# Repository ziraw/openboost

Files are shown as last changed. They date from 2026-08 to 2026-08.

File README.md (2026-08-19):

# Open Source Boost Controller w/ ESP32-C3 SuperMini.  
This is REV2.0 fixing the mistakes of my previous PCB design, it's currently not field tested. 

**The Code was mainly written by an LLM, since I'm extremely inexperienced with coding, please be advised that this is not in any way "safe" to hook up to your engine, please take a minute and review the code yourself and decide for yourself. If you find anything that you might want to change I'm more than happy to see a PR opened!**  
speaking of code, the 2 LEDs are currently not in use.

I'm grabbing the MAP signal off of my gauge atm, which seems to work perfectly fine. You can theoretically hook up a separate sensor to the board itself if you want, although I would never ever use any sort of boost controller without an actual gauge!  

### I/O
It has a 5V output and a sensor passthrough on the JST connector, alongside the main I/O;  
1 - 12V  
2 - GND  
3 - SENS I/O  
4 - SENS I/O  
5 - 5V  
6 - VALVE  

The controller sits between the Valves GND connection and the Chassis to switch it at ~28hz via a PWM signal generated by a PID controller running on the ESP32.
To set Parameters (PID and Boost) it runs a Webserver on it's own WIFI network, which is kind of tedious, but I might add physical controls too a future version, for now the aim of this project is to keep it as **cheap and accessible as possible.**
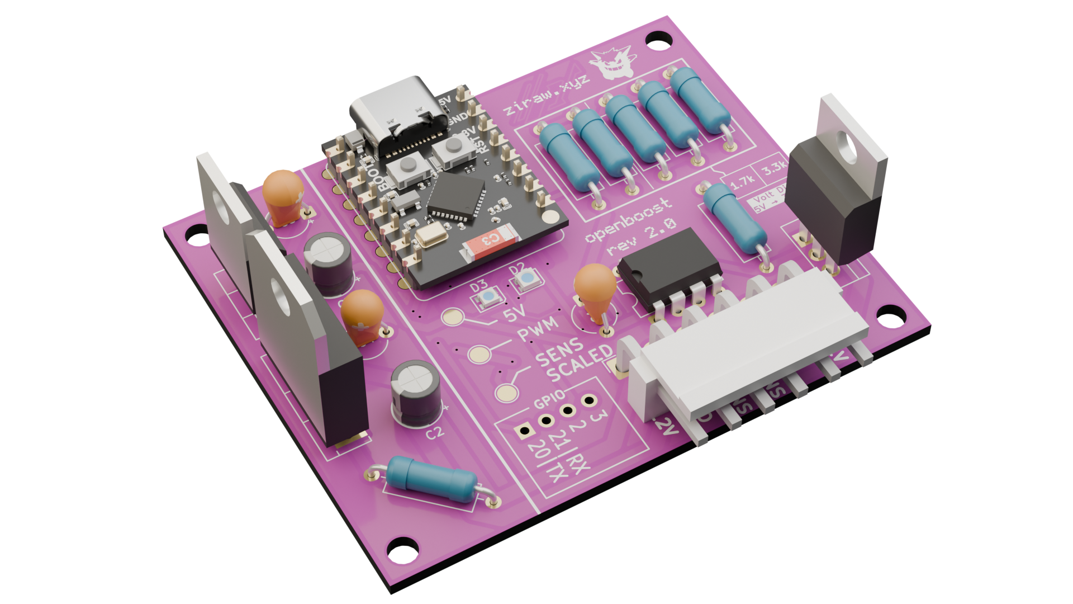
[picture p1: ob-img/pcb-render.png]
3D Render

### BOM (THT unless Specified):
- ESP32-C3 SuperMini  
- IRLZ44N  
- TC4422  
- TIP2955  
- L7805  
- 6P JST-VH Horizontal Connector  
- 2x SMD 2020 WS2812B (not used in Code atm)  
- Various Resistors  
- 2x220uF 16V  
- 3x100nF Ceramic  
- 1N4007 Diode (at Boost Valve)  
- (Pin Sockets for ESP32)

Valve used at Wastegate: BMW N75 Boost Control Valve (on a CA18DET Engine), although any suitable boost/mac valve should be fine to use. You have to hook up above mentioned flyback diode directly to the pins of the valve.

Link to my original reddit post from rev 1: https://www.reddit.com/r/esp32/comments/1vrntt0/i_made_a_boost_controller_with_a_esp32c3_first/

### Schematics
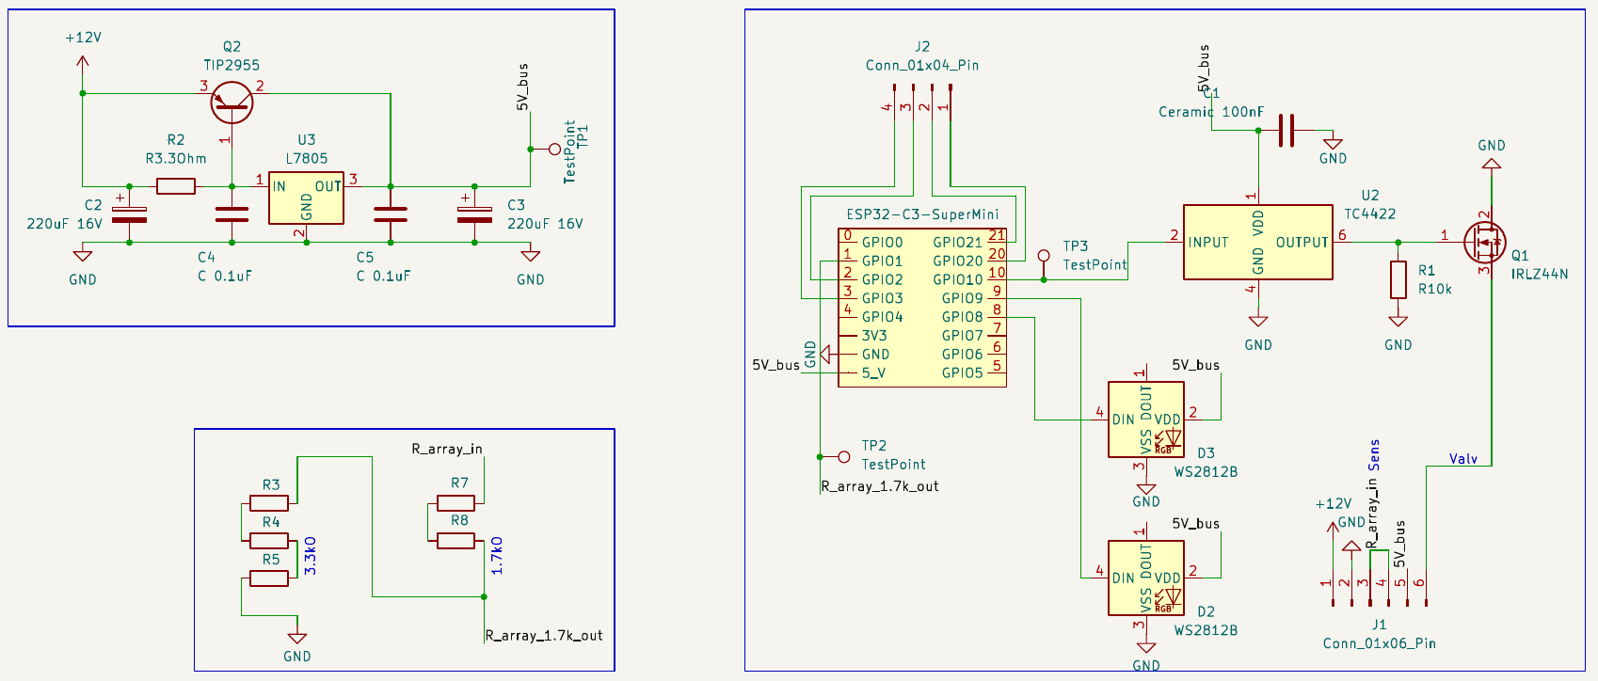
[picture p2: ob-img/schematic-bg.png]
Schematic

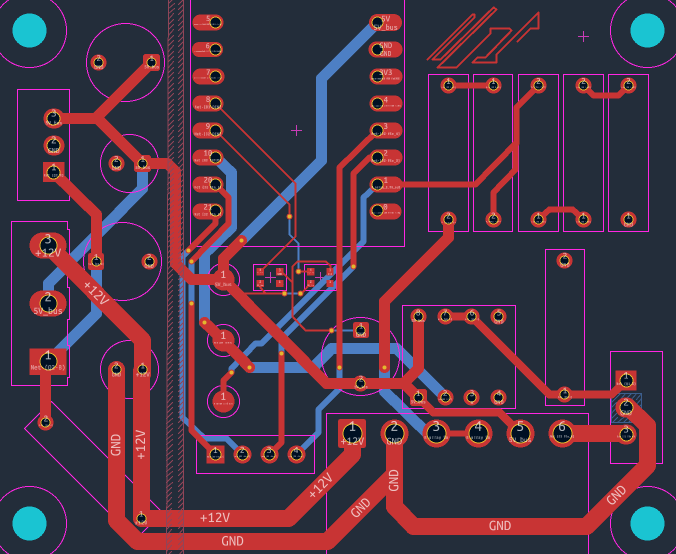
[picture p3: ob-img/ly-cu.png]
CU Layer


Feel free to DM me on reddit: /u/ziraw_tech

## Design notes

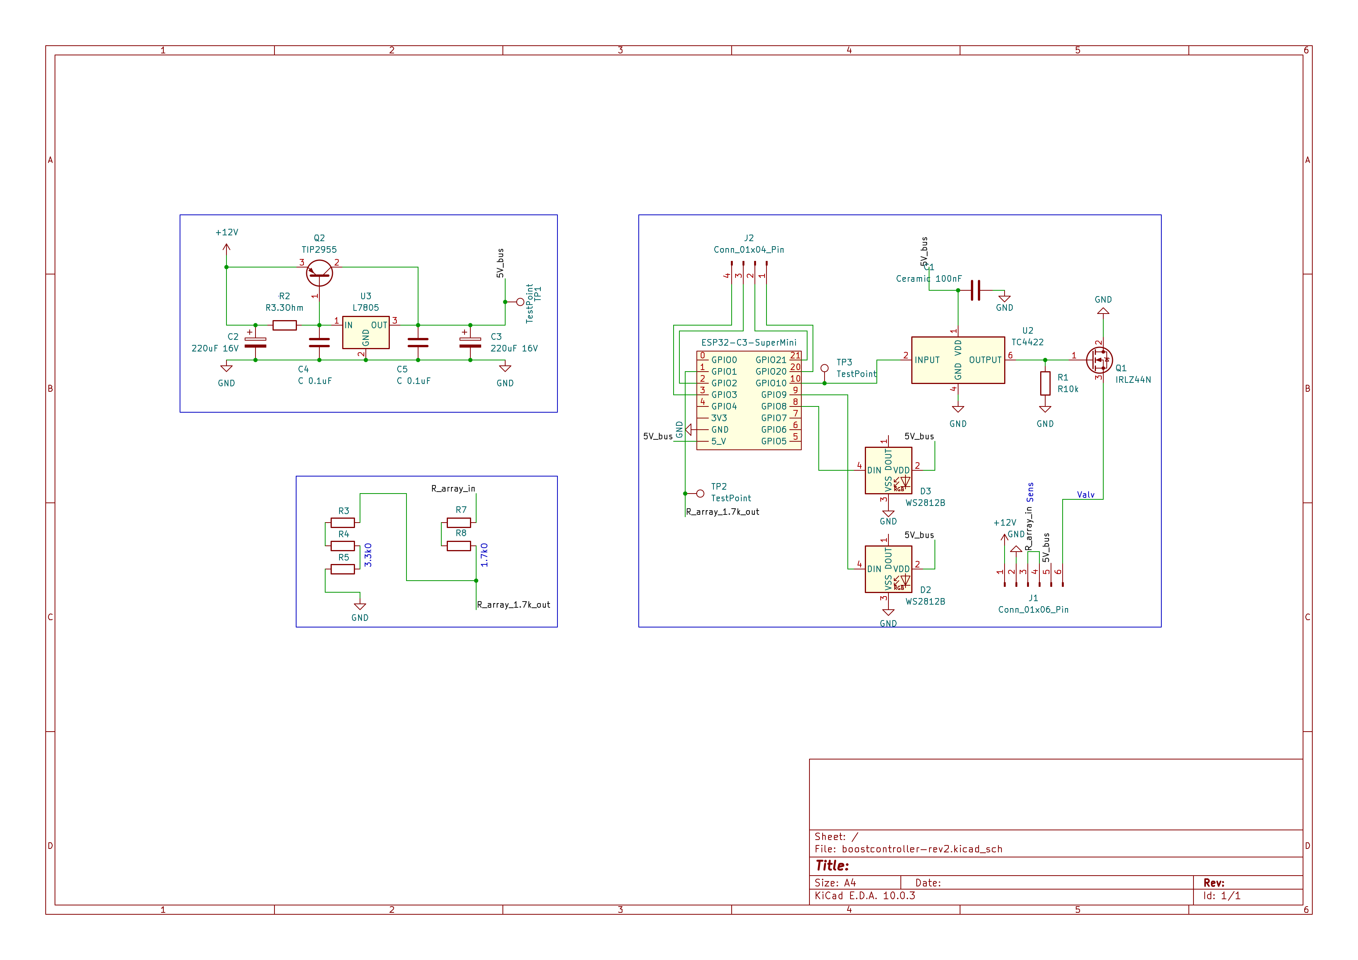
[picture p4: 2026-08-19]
ob-img/schematic.png

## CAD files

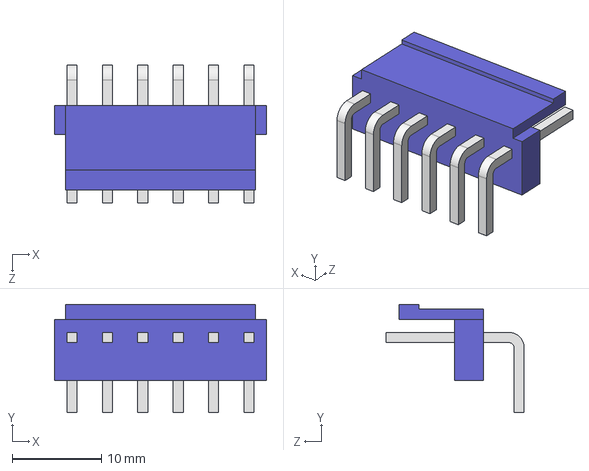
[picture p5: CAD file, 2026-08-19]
3D/B6PS-VH.STEP
23.7 x 12.1 x 15.5 mm

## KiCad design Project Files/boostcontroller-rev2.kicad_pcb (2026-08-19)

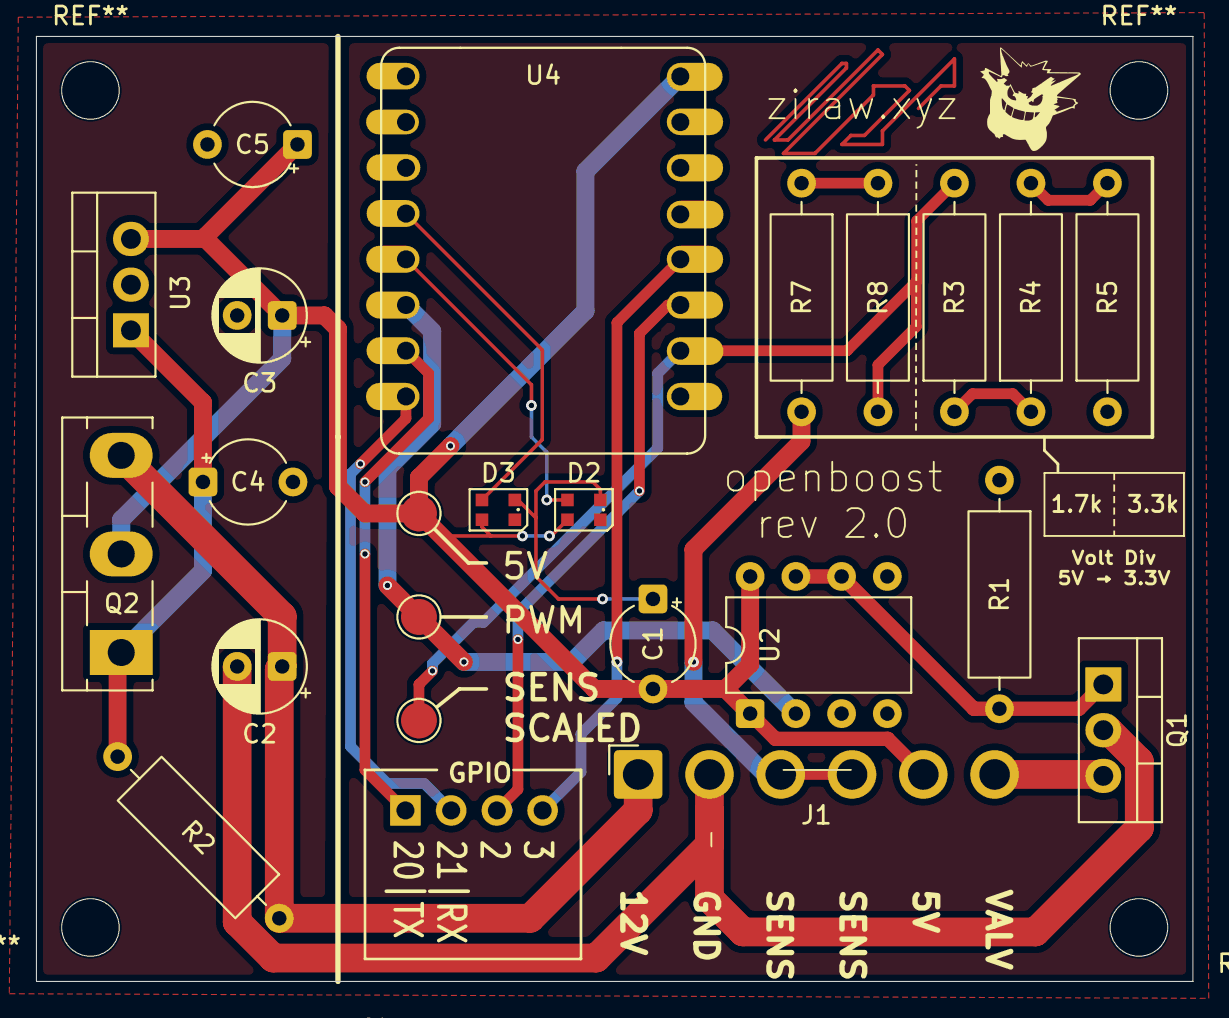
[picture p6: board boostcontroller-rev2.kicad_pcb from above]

Board: 2 copper layers, 64.2 x 52.5 mm, 24 parts (0 on the bottom side), 18 nets.

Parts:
C1: Ceramic 100nF; CP_Radial_Tantal_D4.5mm_P5.00mm
C2, C3: 220uF 16V; CP_Radial_D5.0mm_P2.50mm
C4, C5: C 0.1uF; CP_Radial_Tantal_D4.5mm_P5.00mm
D2, D3: WS2812B; LED_WS2812B-2020_PLCC4_2.0x2.0mm
J1: Conn_01x06_Pin; JST_VH_B6PS-VH_1x06_P3.96mm_Horizontal
J2: Conn_01x04_Pin; PinHeader_1x04_P2.54mm_Vertical
Q1: IRLZ44N; TO-220-3_Vertical
Q2: TIP2955; TO-218-3_Vertical
R1: R10k; R_Axial_DIN0309_L9.0mm_D3.2mm_P12.70mm_Horizontal
R2: R3.3Ohm; R_Axial_DIN0309_L9.0mm_D3.2mm_P12.70mm_Horizontal
R3, R4, R5, R7, R8: R_Axial_DIN0309_L9.0mm_D3.2mm_P12.70mm_Horizontal
TP1, TP2, TP3: TestPoint; TestPoint_Pad_D2.0mm
U2: TC4422; DIP-8_W7.62mm
U3: L7805; TO-220-3_Vertical
U4: ESP32-C3-SuperMini; ESP32-S3-SuperMini

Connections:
+12V: C2.1, J1.1, Q2.3 (E), R2.1
/5V_bus: C1.2, C3.1, C5.1, D2.2 (VDD), D3.2 (VDD), J1.5, Q2.2 (C), TP1.1 (1_1), U2.1 (VDD), U2.8 (VDD), U3.3 (OUT), U4.5V (5_V)
/R_array_1.7k_out: R3.2, R8.2, TP2.1 (1_1), U4.1 (GPIO1)
/R_array_in: J1.3, J1.4, R7.2
GND: C1.1, C2.2, C3.2, C4.2, C5.2, D2.3 (VSS), D3.3 (VSS), J1.2, Q1.2 (D), R1.2, R5.1, U2.4 (GND), U2.5 (GND), U3.2 (GND), U4.GND
unnamed: D2.4 (DIN), U4.9 (GPIO9)
unnamed: D3.4 (DIN), U4.8 (GPIO8)
unnamed: J1.6, Q1.3 (S)
unnamed: J2.1, U4.20 (GPIO20)
unnamed: J2.2, U4.21 (GPIO21)
unnamed: J2.3, U4.2 (GPIO2)
unnamed: J2.4, U4.3 (GPIO3)
unnamed: Q1.1 (G), R1.1, U2.6 (OUTPUT), U2.7 (OUTPUT)
unnamed: C4.1, Q2.1 (B), R2.2, U3.1 (IN)
unnamed: R3.1, R4.1
unnamed: R4.2, R5.2
unnamed: R7.1, R8.1
unnamed: TP3.1 (1_1), U2.2 (INPUT), U4.10 (GPIO10)

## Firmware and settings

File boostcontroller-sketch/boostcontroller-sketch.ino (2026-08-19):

/*
 * ESP32 PID Pressure Controller — Normally-Open Solenoid Valve controlling wastegate
 *
 * Sensor:   0–3.3 V = -1 to +4 bar (raw), then divided by 1.1 for adjustment
 *           → effective display range -1 to ~3.6 bar
 * ADC:      GPIO1
 * MOSFET:   GPIO10  (PWM, max. ~20 kHz(is @ ~20-30hz), 10-bit)
 *           0% duty  = valve fully open  (pressure falls)   → 100% OPEN display
 *           100% duty = valve fully closed (pressure rises) →   0% OPEN display
 *
 * WEB:     http://192.168.4.1
 */

#include <WiFi.h>
#include <WebServer.h>

// ─── WiFi AP credentials ──────────────────────────────────────────────────────
const char* AP_SSID     = "BoostConfig";

// ─── Pin definitions ──────────────────────────────────────────────────────────
#define PIN_ADC   1
#define PIN_PWM   10

// ─── PWM config ───────────────────────────────────────────────────────────────
#define PWM_FREQ  28      // Hz
#define PWM_RES   10      // 10-bit → 0–1023

// ─── Sensor scaling ───────────────────────────────────────────────────────────
// 0 V → -1 bar,  3.3 V → +4 bar  (span = 5 bar over 3.3 V)
// Then divided by 1.1 for physical calibration adjustment
#define PRESSURE_AT_0V    -1.0f   // bar when ADC reads 0 V
#define PRESSURE_AT_3V3   +4.0f   // bar when ADC reads 3.3 V
#define PRESSURE_ADJUST    1.1f   // divisor for calibration

inline float voltsToPressure(float v) {
  float raw = PRESSURE_AT_0V +
              (v / 3.3f) * (PRESSURE_AT_3V3 - PRESSURE_AT_0V);
  return raw / PRESSURE_ADJUST;
}

// ─── PID parameters ───────────────────────────────────────────────────────────
//
//  Tuning direction:
//    Too slow to reach setpoint → raise Kp
//    Oscillates around setpoint → lower Kp, then raise Kd
//    Steady-state offset remains → raise Ki
//    Noisy / chattery valve     → lower Kd
//
float Kp       =  50.0f;
float Ki       =   0.5f;
float Kd       =   0.0f;
float setpoint =   0.95f;   // bar (within -1 … ~3.6 bar)
float outMin   =  -0.0f;    // PWM counts
float outMax   =   511.0f;

// ─── PID state ────────────────────────────────────────────────────────────────
float  integral      = 0.0f;
float  lastInput_bar = 0.0f;
float  pidOutput     = 0.0f;   // 0–1023 (pre-inversion)
float  pressure_bar  = 0.0f;
float  adcVolts      = 0.0f;
unsigned long lastPIDTime = 0;
#define PID_INTERVAL_MS 10     // 100 Hz

// ─── Pressure history for graph (60 s × 2 Hz = 120 samples) ──────────────────
#define HIST_LEN  120
float  pressHist[HIST_LEN];
float  spHist[HIST_LEN];
int    histIdx   = 0;
bool   histFull  = false;
unsigned long lastHistTime = 0;
#define HIST_INTERVAL_MS 500   // store one sample every 500 ms → 60 s window

// ─── Web server ───────────────────────────────────────────────────────────────
WebServer server(80);

// ─── PID compute ─────────────────────────────────────────────────────────────
void computePID() {
  unsigned long now = millis();
  float dt = (now - lastPIDTime) / 1000.0f;
  if (dt < (PID_INTERVAL_MS / 1000.0f)) return;
  lastPIDTime = now;

  // Read ADC — 8-sample average
  int raw = 0;
  for (int i = 0; i < 8; i++) raw += analogRead(PIN_ADC);
  raw /= 8;
  adcVolts     = raw * (3.3f / 4095.0f);
  pressure_bar = voltsToPressure(adcVolts);

  
  // Derivative on measurement (avoids setpoint-change kick)
  float dInput = (pressure_bar - lastInput_bar) / dt;
  float error = setpoint - pressure_bar;

  // Integral with anti-windup
 float pidUnsat = Kp * error + integral - Kd * dInput;
    if (pidUnsat > outMin && pidUnsat < outMax) {
        
        integral += Ki * error * dt;

}


integral  = constrain(integral, -400.0f, 400.0f);
pidOutput = constrain(pidUnsat, outMin, outMax);


  // ── push PWM signal  ───────────────────────────────────────
  uint32_t pwmVal = (uint32_t)pidOutput;

  // safety, if boost is over 0.12 bar over target, valve open.

  if((pressure_bar - setpoint) > 0.12f) {
    ledcWrite(PIN_PWM, 0);
  } else {
    ledcWrite(PIN_PWM, pwmVal);
  }
  
  lastInput_bar = pressure_bar;
  
  // ── History log ──────────────────────────────────────────────────────────
  if ((now - lastHistTime) >= HIST_INTERVAL_MS) {
    lastHistTime = now;
    pressHist[histIdx] = pressure_bar;
    spHist[histIdx]    = setpoint;
    histIdx = (histIdx + 1) % HIST_LEN;
    if (histIdx == 0) histFull = true;
  }

  if (Serial) {
    // dutyOpen: 0% = closed, 100% = open (inverted from pwmVal)
    float valveOpenPct = (outMax > 0) ? (1.0f - pidOutput / outMax) * 100.0f : 0.0f;
    Serial.printf("[PID] Target=%.3fbar  BoostNow=%.3fbar  err=%.4f  PWM(0-1023)=%u  OpenPct=%.1f%%\n",
                  setpoint, pressure_bar, error, pwmVal, valveOpenPct);
  }

  if (pressure_bar < -0.89) {
    Serial.printf(" Sensor Disconnect? ");
  }

}

// ─── History JSON ─────────────────────────────────────────────────────────────
// Returns arrays ordered oldest→newest
void handleHistory() {
  int count = histFull ? HIST_LEN : histIdx;
  int start = histFull ? histIdx  : 0;

  String json = "{\"pressure\":[";
  for (int i = 0; i < count; i++) {
    int idx = (start + i) % HIST_LEN;
    if (i) json += ',';
    json += String(pressHist[idx], 3);
  }
  json += "],\"setpoint\":[";
  for (int i = 0; i < count; i++) {
    int idx = (start + i) % HIST_LEN;
    if (i) json += ',';
    json += String(spHist[idx], 3);
  }
  json += "]}";
  server.send(200, "application/json", json);
}

// ─── HTML page ────────────────────────────────────────────────────────────────
String buildPage(String message = "") {
  // Duty cycle expressed as % OPEN (100% = valve wide open, 0% = fully closed)
  uint32_t pwmVal = (uint32_t)(outMax - constrain(pidOutput, outMin, outMax));
  float dutyOpenPct = (1.0f - (float)pwmVal / outMax) * 100.0f;

  // Gauge fill: map -1…+2 bar (3 bar span) to 0–100%
  float gaugePct = ((pressure_bar - (-1.0f)) / 3.0f) * 100.0f;
  gaugePct = constrain(gaugePct, 0.0f, 100.0f);

  String html = R"rawhtml(<!DOCTYPE html>
<html lang="en">
<head>
<meta charset="UTF-8">
<meta name="viewport" content="width=device-width, initial-scale=1.0">
<title>Pressure PID</title>
<style>
  * { box-sizing: border-box; margin: 0; padding: 0; }
  :root {
    --bg:      #0f1117;
    --surface: #1a1d27;
    --border:  #2e3147;
    --accent:  #4f8ef7;
    --accent2: #7c5cfc;
    --text:    #e8eaf0;
    --muted:   #6b7280;
    --success: #34d399;
    --warn:    #fbbf24;
    --danger:  #ef4444;
    --radius:  12px;
  }
  body {
    background: var(--bg); color: var(--text);
    font-family: 'Segoe UI', system-ui, sans-serif;
    min-height: 100vh; display: flex;
    align-items: flex-start; justify-content: center; padding: 24px;
  }
  .card {
    background: var(--surface); border: 1px solid var(--border);
    border-radius: var(--radius); width: 100%; max-width: 500px;
    padding: 32px 28px;
  }
  .header { display: flex; align-items: center; gap: 12px; margin-bottom: 8px; }
  .dot {
    width: 10px; height: 10px; border-radius: 50%;
    background: var(--success); box-shadow: 0 0 8px var(--success); flex-shrink: 0;
  }
  h1 { font-size: 1.1rem; font-weight: 600; }
  .subtitle { font-size: 0.75rem; color: var(--muted); margin-top: 2px; }

  /* view toggle */
  .view-toggle {
    display: flex; gap: 8px; margin: 16px 0 0;
  }
  .btn-view {
    flex: 1; padding: 9px 0;
    border-radius: 8px; font-size: 0.82rem; font-weight: 600;
    cursor: pointer; border: 1px solid var(--border);
    transition: background 0.15s, color 0.15s;
  }
  .btn-view.active {
    background: linear-gradient(135deg, var(--accent), var(--accent2));
    border-color: transparent; color: #fff;
  }
  .btn-view:not(.active) { background: var(--bg); color: var(--muted); }

  .status-bar {
    display: flex; gap: 8px; margin: 16px 0 20px;
    padding: 14px; background: var(--bg);
    border: 1px solid var(--border); border-radius: 8px;
  }
  .stat { flex: 1; text-align: center; }
  .stat-val { font-size: 1.1rem; font-weight: 700; color: var(--accent); }
  .stat-val.warn   { color: var(--warn); }
  .stat-val.danger { color: var(--danger); }
  .stat-lbl { color: var(--muted); font-size: 0.68rem; margin-top: 3px; }

  /* ── Gauge ─── */
  .gauge-wrap { margin: 0 0 20px; }
  .gauge-track {
    height: 8px; background: var(--border); border-radius: 99px;
    position: relative; overflow: visible;
  }
  .gauge-fill {
    height: 100%; border-radius: 99px;
    background: linear-gradient(90deg, #6b7280 0%, #34d399 20%, #4f8ef7 67%, #ef4444 100%);
    transition: width 0.4s ease;
  }
  /* zero-bar marker at 33.3% (1 bar into 3-bar span) */
  .gauge-zero {
    position: absolute; top: -4px; bottom: -4px;
    left: 33.33%; width: 2px;
    background: var(--muted); border-radius: 1px;
  }
  .gauge-labels {
    display: flex; justify-content: space-between;
    font-size: 0.65rem; color: var(--muted); margin-top: 5px;
    position: relative;
  }
  .gauge-labels span:nth-child(2) {
    position: absolute; left: 33.33%; transform: translateX(-50%);
  }

  /* ── Graph view ─── */
  #graph-panel { display: none; margin-bottom: 20px; }
  #graph-panel canvas {
    width: 100%; height: 180px; border-radius: 8px;
    background: var(--bg); border: 1px solid var(--border);
  }
  .graph-legend {
    display: flex; gap: 16px; justify-content: center;
    font-size: 0.72rem; color: var(--muted); margin-top: 8px;
  }
  .leg-dot { display: inline-block; width: 10px; height: 10px;
    border-radius: 50%; margin-right: 4px; vertical-align: middle; }

  .section-label {
    font-size: 0.7rem; font-weight: 700; letter-spacing: 0.1em;
    text-transform: uppercase; color: var(--muted);
    margin: 20px 0 12px; display: flex; align-items: center; gap: 8px;
  }
  .section-label::after { content:''; flex:1; height:1px; background:var(--border); }

  .field { margin-bottom: 14px; }
  label {
    display: flex; align-items: baseline; gap: 8px;
    margin-bottom: 6px; font-size: 0.82rem; font-weight: 600;
    letter-spacing: 0.06em; text-transform: uppercase; color: var(--muted);
  }
  .badge {
    font-size: 0.7rem; padding: 1px 7px; border-radius: 99px;
    font-weight: 500; text-transform: none; letter-spacing: 0; color: #fff;
    background: linear-gradient(135deg, var(--accent), var(--accent2));
  }
  .badge.sp  { background: linear-gradient(135deg, #f97316, #ef4444); }
  .badge.lim { background: linear-gradient(135deg, #6b7280, #4b5563); }
  input[type="number"] {
    width: 100%; background: var(--bg); border: 1px solid var(--border);
    border-radius: 8px; color: var(--text); font-size: 1rem;
    padding: 10px 14px; outline: none; transition: border-color 0.15s;
  }
  input[type="number"]:focus {
    border-color: var(--accent);
    box-shadow: 0 0 0 3px rgba(79,142,247,0.15);
  }
  .row { display: flex; gap: 10px; }
  .row .field { flex: 1; }
  button.btn-apply {
    width: 100%; padding: 12px;
    background: linear-gradient(135deg, var(--accent), var(--accent2));
    border: none; border-radius: 8px; color: #fff;
    font-size: 0.95rem; font-weight: 600; cursor: pointer;
    transition: opacity 0.15s, transform 0.1s; margin-top: 6px;
  }
  button.btn-apply:hover  { opacity: 0.9; }
  button.btn-apply:active { transform: scale(0.98); }
  .btn-reset {
    width: 100%; background: #1f2230; border: 1px solid var(--border);
    border-radius: 8px; color: var(--muted); font-size: 0.82rem;
    padding: 9px; margin-top: 8px; cursor: pointer;
    transition: color 0.15s;
  }
  .btn-reset:hover { color: var(--text); }
  .toast {
    margin-top: 14px; padding: 10px 14px; border-radius: 8px;
    font-size: 0.85rem; text-align: center;
    background: rgba(52,211,153,0.12); border: 1px solid rgba(52,211,153,0.3);
    color: var(--success);
  }
  .note { font-size: 0.72rem; color: var(--muted); margin-top: 10px; text-align: center; }
</style>
</head>
<body>
<div class="card">
  <div class="header">
    <div class="dot"></div>
    <div>
      <h1>Pressure PID</h1>
      <div class="subtitle">ESP32 &nbsp;·&nbsp; Normally-open valve &nbsp;·&nbsp; −1 to +4 bar</div>
    </div>
  </div>

  <!-- View toggle -->
  <div class="view-toggle">
    <button class="btn-view active" id="btn-dash" onclick="switchView('dash')">Dashboard</button>
    <button class="btn-view"        id="btn-graph" onclick="switchView('graph')">Graph (60 s)</button>
  </div>

  <!-- Live status bar (always visible) -->
  <div class="status-bar">
    <div class="stat">
      <div class="stat-val" id="lv-pressure">—</div>
      <div class="stat-lbl">Pressure (bar)</div>
    </div>
    <div class="stat">
      <div class="stat-val" id="lv-sp">—</div>
      <div class="stat-lbl">Setpoint (bar)</div>
    </div>
    <div class="stat">
      <div class="stat-val" id="lv-err">—</div>
      <div class="stat-lbl">Error (bar)</div>
    </div>
    <div class="stat">
      <div class="stat-val" id="lv-duty">—</div>
      <div class="stat-lbl">Valve open %</div>
    </div>
  </div>

  <!-- Gauge (-1 to +2 bar display range) -->
  <div class="gauge-wrap">
    <div class="gauge-track">
      <div class="gauge-fill" id="gauge" style="width:0%"></div>
      <div class="gauge-zero"></div>
    </div>
    <div class="gauge-labels">
      <span>−1 bar</span>
      <span>0 bar</span>
      <span style="margin-left:auto">+2 bar</span>
    </div>
  </div>

  <!-- Graph panel (hidden by default) -->
  <div id="graph-panel">
    <canvas id="graph-canvas" width="440" height="180"></canvas>
    <div class="graph-legend">
      <span><span class="leg-dot" style="background:#4f8ef7"></span>Pressure</span>
      <span><span class="leg-dot" style="background:#f97316"></span>Setpoint</span>
    </div>
  </div>

  <!-- Settings form (dashboard view) -->
  <div id="dash-panel">
    <form method="POST" action="/set">
      <div class="section-label">Setpoint</div>
      <div class="field">
        <label>Setpoint <span class="badge sp">bar</span></label>
        <input type="number" step="0.01" min="-1" max="4" name="setpoint" value=")rawhtml";
  html += String(setpoint, 3);
  html += R"rawhtml(">
      </div>

      <div class="section-label">PID Gains</div>
      <div class="row">
        <div class="field">
          <label>Kp <span class="badge">prop</span></label>
          <input type="number" step="any" name="Kp" value=")rawhtml";
  html += String(Kp, 4);
  html += R"rawhtml(">
        </div>
        <div class="field">
          <label>Ki <span class="badge">integ</span></label>
          <input type="number" step="any" name="Ki" value=")rawhtml";
  html += String(Ki, 4);
  html += R"rawhtml(">
        </div>
      </div>
      <div class="field">
        <label>Kd <span class="badge">deriv</span></label>
        <input type="number" step="any" name="Kd" value=")rawhtml";
  html += String(Kd, 4);
  html += R"rawhtml(">
      </div>

      <div class="section-label">Output Clamp <span class="badge lim">PWM counts 0–1023</span></div>
      <div class="row">
        <div class="field">
          <label>Min</label>
          <input type="number" step="1" min="0" max="1023" name="outMin" value=")rawhtml";
  html += String((int)outMin);
  html += R"rawhtml(">
        </div>
        <div class="field">
          <label>Max</label>
          <input type="number" step="1" min="0" max="1023" name="outMax" value=")rawhtml";
  html += String((int)outMax);
  html += R"rawhtml(">
        </div>
      </div>

      <button type="submit" class="btn-apply">Apply</button>
      <button type="submit" formaction="/reset" class="btn-reset">Reset Integral</button>
    </form>
    <p class="note">Normally-open valve: 100% open = no PWM · 0% open = full PWM</p>
  </div>
  )rawhtml";

  if (message.length() > 0)
    html += "<div class=\"toast\">" + message + "</div>";

  html += R"rawhtml(
</div><!-- .card -->

<script>
// ── View switching ────────────────────────────────────────────────────────────
let currentView = 'dash';
function switchView(v) {
  currentView = v;
  document.getElementById('dash-panel').style.display  = (v === 'dash')  ? '' : 'none';
  document.getElementById('graph-panel').style.display = (v === 'graph') ? 'block' : 'none';
  document.getElementById('btn-dash').classList.toggle('active',  v === 'dash');
  document.getElementById('btn-graph').classList.toggle('active', v === 'graph');
  if (v === 'graph') drawGraph();
}

// ── Canvas graph ──────────────────────────────────────────────────────────────
let graphData = { pressure: [], setpoint: [] };

function drawGraph() {
  const canvas = document.getElementById('graph-canvas');
  const ctx    = canvas.getContext('2d');
  const W = canvas.width, H = canvas.height;
  const PAD = { top: 12, right: 10, bottom: 24, left: 38 };
  const pArr = graphData.pressure;
  const sArr = graphData.setpoint;
  const n    = pArr.length;

  ctx.clearRect(0, 0, W, H);

  // Background
  ctx.fillStyle = '#0f1117';
  ctx.fillRect(0, 0, W, H);

  // Y range: -1 to +2 bar
  const yMin = -1.0, yMax = 2.0;
  const ySpan = yMax - yMin;
  const plotW = W - PAD.left - PAD.right;
  const plotH = H - PAD.top  - PAD.bottom;

  function px(i) { return PAD.left + (n > 1 ? (i / (n - 1)) * plotW : plotW / 2); }
  function py(v) { return PAD.top  + (1 - (v - yMin) / ySpan) * plotH; }

  // Grid lines at -1, 0, 0.5, 1, 1.5, 2
  const gridY = [-1, -0.5, 0, 0.5, 1.0, 1.5, 2.0];
  gridY.forEach(g => {
    const y = py(g);
    ctx.beginPath();
    ctx.strokeStyle = g === 0 ? '#3a3d55' : '#232537';
    ctx.lineWidth   = g === 0 ? 1.5 : 1;
    ctx.setLineDash(g === 0 ? [] : [4, 4]);
    ctx.moveTo(PAD.left, y); ctx.lineTo(PAD.left + plotW, y);
    ctx.stroke();
    ctx.setLineDash([]);
    ctx.fillStyle = '#6b7280'; ctx.font = '10px system-ui';
    ctx.textAlign = 'right';
    ctx.fillText(g.toFixed(1), PAD.left - 4, y + 3.5);
  });

  // X axis label
  ctx.fillStyle = '#6b7280'; ctx.font = '9px system-ui'; ctx.textAlign = 'center';
  ctx.fillText('−60 s', PAD.left, H - 4);
  ctx.fillText('now',   PAD.left + plotW, H - 4);

  if (n < 2) return;

  // Setpoint line (orange dashed)
  ctx.beginPath(); ctx.strokeStyle = '#f97316'; ctx.lineWidth = 1.5; ctx.setLineDash([6, 4]);
  sArr.forEach((v, i) => i === 0 ? ctx.moveTo(px(i), py(v)) : ctx.lineTo(px(i), py(v)));
  ctx.stroke(); ctx.setLineDash([]);

  // Pressure line (blue solid)
  ctx.beginPath(); ctx.strokeStyle = '#4f8ef7'; ctx.lineWidth = 2;
  pArr.forEach((v, i) => i === 0 ? ctx.moveTo(px(i), py(v)) : ctx.lineTo(px(i), py(v)));
  ctx.stroke();
}

// ── Live values refresh ───────────────────────────────────────────────────────
function refresh() {
  fetch('/values').then(r => r.json()).then(d => {
    // Pressure: show with sign
    const pEl = document.getElementById('lv-pressure');
    pEl.textContent = (d.pressure >= 0 ? '+' : '') + d.pressure.toFixed(3);
    pEl.className   = 'stat-val' + (d.pressure < 0 ? ' danger' : '');

    document.getElementById('lv-sp').textContent = (d.setpoint >= 0 ? '+' : '') + d.setpoint.toFixed(3);

    const err   = d.setpoint - d.pressure;
    const errEl = document.getElementById('lv-err');
    errEl.textContent = (err >= 0 ? '+' : '') + err.toFixed(3);
    errEl.className   = 'stat-val' + (Math.abs(err) > 0.15 ? ' warn' : '');

    // Valve open %: 100% = wide open, 0% = fully closed
    document.getElementById('lv-duty').textContent = d.valveOpen.toFixed(1) + '%';

    // Gauge: map -1…+2 bar to 0–100% (3 bar span)
    const gaugePct = Math.min(100, Math.max(0, ((d.pressure - (-1.0)) / 3.0) * 100));
    document.getElementById('gauge').style.width = gaugePct.toFixed(1) + '%';
  }).catch(() => {});

  if (currentView === 'graph') {
    fetch('/history').then(r => r.json()).then(d => {
      graphData = d;
      drawGraph();
    }).catch(() => {});
  }
}
setInterval(refresh, 400);
refresh();
</script>
</body>
</html>)rawhtml";

  return html;
}

// ─── Routes ───────────────────────────────────────────────────────────────────
void handleRoot() { server.send(200, "text/html", buildPage()); }

void handleSet() {
  if (server.hasArg("Kp"))       Kp       = server.arg("Kp").toFloat();
  if (server.hasArg("Ki"))       Ki       = server.arg("Ki").toFloat();
  if (server.hasArg("Kd"))       Kd       = server.arg("Kd").toFloat();
  if (server.hasArg("setpoint")) setpoint = server.arg("setpoint").toFloat();
  if (server.hasArg("outMin"))   outMin   = server.arg("outMin").toFloat();
  if (server.hasArg("outMax"))   outMax   = server.arg("outMax").toFloat();

  setpoint = constrain(setpoint, -1.0f, 2.0f);
  outMin   = constrain(outMin,    0.0f, 1023.0f);
  outMax   = constrain(outMax,    0.0f, 1023.0f);
  if (outMin > outMax) outMin = outMax;

  Serial.printf("[Config] Kp=%.3f Ki=%.3f Kd=%.3f SP=%.3fbar out=[%.0f,%.0f]\n",
                Kp, Ki, Kd, setpoint, outMin, outMax);

  server.send(200, "text/html",
    buildPage("✓ Applied — SP=" + String(setpoint, 2) + " bar"
              "  Kp=" + String(Kp, 2) +
              "  Ki=" + String(Ki, 2) +
              "  Kd=" + String(Kd, 2)));
}

void handleReset() {
  integral      = 0.0f;
  lastInput_bar = pressure_bar;
  Serial.println("[PID] Integral reset.");
  server.send(200, "text/html", buildPage("✓ Integral reset."));
}

void handleValues() {
  float valveOpen = (outMax > 0) ? (1.0f - constrain(pidOutput, outMin, outMax) / outMax) * 100.0f : 0.0f;  
    
    // 100% = fully open = wastegate pressure. / 0% = fully closed = max turbo pressure

  String json =
    "{\"pressure\":"  + String(pressure_bar, 4) +
    ",\"setpoint\":"  + String(setpoint,      4) +
    ",\"output\":"    + String(pidOutput,      2) +
    ",\"valveOpen\":" + String(valveOpen,      2) +
    ",\"Kp\":"        + String(Kp, 4) +
    ",\"Ki\":"        + String(Ki, 4) +
    ",\"Kd\":"        + String(Kd, 4) +
    ",\"outMin\":"    + String(outMin, 0) +
    ",\"outMax\":"    + String(outMax, 0) + "}";
  server.send(200, "application/json", json);
}
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
void loop() {
  server.handleClient();
  computePID();
}
